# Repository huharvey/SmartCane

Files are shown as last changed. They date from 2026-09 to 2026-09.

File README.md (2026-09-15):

# SmartCane

基于 **ESP32-S3-CAM** 的智能拐杖课程原型：近障提示、跌倒告警、心率/血氧采集、Wi-Fi 图传、GPS 定位，以及 MQTT 远程监护网页。

本仓库是结题归档版本。固件对应实机调试最终代码；电路对应嘉立创工程 `智能拐杖电路设计_1.eprj2`；结构对应 `结构` 目录完整文件。跌倒检测与 MAX30102/节律筛查仅为课程演示，**不能作为医疗或人身安全认证结论**。

## 仓库结构

```text
SmartCane/
├─ firmware/          ESP32 固件、上位机、远程网页、验收材料
├─ hardware/          嘉立创电路工程、Gerber、原理图 PDF
├─ mechanical/        SolidWorks 零件/装配体、STEP、打印文件
├─ docs/              开题答辩、中期进展、结题报告（已去标识）
└─ media/             结构照片、调试截图、功能演示视频
```

| 路径 | 说明 |
|---|---|
| `firmware/` | PlatformIO / Arduino 主工程。详细说明见 [firmware/README.md](firmware/README.md) |
| `firmware/src/` | 驱动、FreeRTOS 任务、跌倒检测、MQTT、摄像头服务 |
| `firmware/upper_computer/` | Windows PyQt 上位机（串口遥测、图传、地图） |
| `firmware/remote_dashboard/` | MQTT 远程监护网页（Python） |
| `firmware/ml/rhythm/` | 节律筛查离线训练脚本（公开 MIMIC 数据包需自行下载） |
| `hardware/智能拐杖电路设计.eprj2` | 最终电路 PCB 工程 |
| `hardware/Gerber_PCB.zip` | 制板 Gerber |
| `mechanical/` | 壳体、装配体及厂商库模型（按结题结构目录原样归档） |
| `docs/` | 课程报告与答辩材料 |
| `media/videos/` | 心率血氧、跌倒告警、超声测距、实时图传 |

## 功能概览

- HC-SR04（I2C）、JY901S、ATGM336H、BH1750、SSD1306、SOS 按键、蜂鸣器、照明
- OV2640 MJPEG 图传与本地网页控制
- 双路径跌倒检测（冲击路径 + 深度失重补偿），SOS/跌倒锁存
- MAX30102 心率/血氧原型与端侧节律筛查（非医疗）
- MQTT TLS 公网遥测 + 独立远程监护网页
- 上位机：串口 JSON、图传、GPS 地图、轨迹导入

当前台架配置中，MAX30102 与超声波模块共用 I2C 地址 `0x57`，固件默认关闭超声波和 OLED，只启用 MAX30102。若要同时使用，必须在硬件上分离总线。

## 快速开始（固件）

1. 用 VS Code / PlatformIO 打开 `firmware/`。
2. 编辑 `firmware/src/config/UserConfig.h`：填写 Wi-Fi、高德静态地图 Key、MQTT Broker（仓库内均为空占位符）。
3. 选择 `esp32-s3-cam`，Build / Upload。板型为 GOOUUU ESP32-S3-CAM（8 MB Flash + OPI PSRAM），USB CDC On Boot 需关闭。
4. 串口 115200。上位机见 `firmware/upper_computer/README.md`。

热点回退（SSID 留空时）：

- SSID：`SmartCane-Camera`
- 密码：`12345678`
- 页面：`http://192.168.4.1/`

## 硬件要点

- 主控：ESP32-S3-CAM + OV2640
- I2C：SDA GPIO41、SCL GPIO42（3.3 V 上拉）
- IMU：GPIO39/38；GPS：GPIO47/21；SOS：GPIO40；蜂鸣器：GPIO1；照明：GPIO14
- 原理图 PDF 与 Gerber 在 `hardware/`；结构件在 `mechanical/`

## 归档说明

- 已移除学号、姓名等课程标识；报告正文中的姓名已替换为成员 A/B/C。
- Wi-Fi 密码、高德 Key、EMQX 账号已换成空占位符；MQTT 默认关闭。本地烧录前请自行填写。
- 运行日志、原始 MIMIC zip、含密钥的 `.bin` 固件未入库。
- 结题答辩 PPT 因体积超过 GitHub 单文件限制未放入仓库；开题/中期 PPT 与结题报告在 `docs/`。

## 许可与声明

课程项目归档，仅供学习交流。传感器告警、跌倒检测和生理信号结果均未经医疗器械验证。

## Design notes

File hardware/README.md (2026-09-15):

# 电路与 PCB

- `智能拐杖电路设计.eprj2`：嘉立创 EDA 最终工程（对应原 `智能拐杖电路设计_1.eprj2`）
- `Gerber_PCB.zip`：制板 Gerber
- `SCH_Schematic1.pdf` / `SCH_Schematic2.pdf` / `SCH_Schematic5.pdf`：原理图导出

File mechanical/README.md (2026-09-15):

# 结构件

结题时的完整结构目录归档，含自制壳体、装配体、STEP 以及厂商库模型。

主要文件：

- `装配体.SLDASM`：总装配
- `01_亚克力筒.SLDPRT`、`02_摄像头和灯泡载体.*`、`04_上半后部分.*`、`05_下半部分.*` 等自制件
- `电路连接件/`：主板底座、电池底座等
- `MAIN.step` / `UPPER.step` / `LOWER.step` / `POWER.step`：导出 STEP

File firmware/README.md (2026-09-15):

# ESP32-S3-CAM 智能拐杖 Arduino 工程

本目录是仓库中的固件子工程；项目总览见仓库根目录 [README.md](../README.md)。

本工程对应 **GOOUUU ESP32-S3-CAM + OV2640**，并按所给三页原理图配置引脚。传感器、决策、执行器、网络和串口已按 FreeRTOS 多任务运行；相机、Wi-Fi 和 HTTP 服务来自 ESP32 Arduino Core。

## 详细文档

- [工程架构与每个文件的作用](docs/01-工程架构与文件说明.md)
- [ESP32-S3 Arduino 开发与调试指南（零基础）](docs/02-ESP32-Arduino开发与调试指南.md)
- [ESP32-S3-CAM 每 10 秒 Wi-Fi 图传 Demo](demos/wifi_snapshot_10s/README.md)
- [上位机与 SC1 串口通信协议](docs/03-上位机与通信协议.md)
- [硬件现状与下一阶段特色方案](docs/04-硬件现状与下一阶段特色方案.md)
- [FreeRTOS 联调与测试操作手册](docs/06-FreeRTOS联调与测试操作手册.md)
- [跌倒确认与 MAX30102 调试](docs/07-跌倒确认与MAX30102调试.md)
- [TinyML 节律筛查与 MQTT 公网接入](docs/08-TinyML节律筛查与MQTT公网接入.md)
- [MAX30102 与节律筛查调试指南](docs/09-MAX30102与节律筛查调试指南.md)
- [MAX30102 首轮无参考仪器数据分析](docs/10-MAX30102首轮无参考仪器数据分析.md)
- [公网监护网页与部署说明](remote_dashboard/README.md)
- [本轮验收进展与后续任务](验收材料/SmartCane555_本轮代码改动_调试进展与后续任务.md)
- [Windows 上位机使用说明](upper_computer/README.md)

## 本次集成交付边界

已集成并作为本次交付验收项：各传感器原始数据采集、OLED/蜂鸣器/照明硬件接口、CH340 串口 JSON 遥测与命令、Wi-Fi 摄像头服务、上位机传感器显示、MJPEG 图传、GPS 地图和 GeoJSON/GPX/KML 导入。

本次还完成了双核 FreeRTOS 调度、队列/互斥保护、经独立样本验收的双路径跌倒检测、MAX30102 心率/血氧原型、PPG 质量与 baseline 节律筛查，以及 MQTT TLS 公网遥测和独立远程监护网页。跌倒阈值已按本项目样本冻结，但这些结果仍属于课程原型，不能作为医疗或人身安全认证结论。

公网网页曾部署到云主机做课程演示。仓库中的 MQTT / Wi-Fi / 地图密钥已清空，本地复现时请自行填写 `UserConfig.h` 与 `remote_dashboard/.env`。域名和 HTTPS 是后续安全升级项，不是课程演示的硬性前置条件。

## 给后续的阅读入口

1. 先看 `src/model/SystemState.h`：这是统一的传感器数据结构、单位和有效性约定；
2. 再看 `src/app/SmartCaneApp.cpp` 的 `updateSensors()`：这里汇总各驱动的新数据并处理超时；
3. 需要核对原始协议时再进入 `src/drivers/`，不要在算法中直接读 UART/I2C；
4. 算法建议在 `updateSensors()` 之后消费 `sensors_`，输出事件交给控制层；
5. 串口/HTTP 对外字段以 `docs/03-上位机与通信协议.md` 为准。

## 已实现功能

- HC-SR04 2021 UART/IIC 版：I2C 非阻塞测距，默认地址 `0x57`；当前 MAX30102 台架配置因地址冲突暂时停用
- JY901S：解析 `0x55` 帧的加速度、角速度和欧拉角
- ATGM336H：校验并解析 RMC/GGA NMEA 语句
- BH1750 GY-302：自动识别 `0x23`/`0x5C` 地址并读取照度
- SSD1306 128x64：自带轻量显示驱动和英数字体
- SOS 按键、蜂鸣器和照明 LED：分级节奏、锁存、取消及网页/串口控制已实现
- 跌倒检测：严格冲击路径与深度失重补偿路径已实现，并完成独立样本验收
- MAX30102：心率、血氧原型、PPG 质量、IBI/HRV 特征和佩戴状态检测
- 节律筛查：端侧特征提取与 baseline TinyML 推理链已接通；训练模型替换仍待完成
- MQTT 公网通信：通过 TLS 发布 presence、telemetry、vitals、gps、event 五类主题，远程控制默认关闭
- Wi-Fi：优先连接路由器，失败后建立 `SmartCane-Camera` 热点
- OV2640：网页 MJPEG 图传、JPEG 抓拍、JSON 状态和网页控制
- 上位机：串口全量遥测/控制、Wi-Fi 图传、GPS 在线/离线矢量地图、轨迹导入
- 公网监护网页：Python 后端订阅 MQTT，向浏览器提供只读状态、SSE 实时刷新、告警事件和 GPS 地图

> 跌倒检测和 MAX30102/节律筛查均为课程原型。现有验收只能说明在本项目采集样本中通过，不能替代医疗器械验证或真实人身安全认证。

## 引脚表

| 功能 | 模块/信号 | ESP32-S3 GPIO | 板卡排针 | 方向（以 ESP32 为准） |
|---|---|---:|---:|---|
| I2C SDA | 超声波、BH1750、OLED 共用 | 41 | U3-15 | 双向 |
| I2C SCL | 超声波、BH1750、OLED 共用 | 42 | U3-16 | 输出 |
| JY901S TX | IMU 数据到主控 | 39 | U3-13 | RX |
| JY901S RX | 主控命令到 IMU | 38 | U3-12 | TX |
| ATGM336H TX | GPS 数据到主控 | 47 | U3-5 | RX |
| ATGM336H RX | 主控命令到 GPS | 21 | U3-4 | TX |
| SOS | 按下为高电平 | 40 | U3-14 | 输入 |
| 蜂鸣器 | MOS 管栅极，高电平响 | 1 | U3-18 | 输出 |
| LED/照明 | 高电平开 | 14 | U2-19 | 输出 |

相机引脚按板卡原理图固定为：SCCB `GPIO4/5`、VSYNC `6`、HREF `7`、XCLK `15`、PCLK `13`、数据线 `8/9/10/11/12/16/17/18`。这些脚不可再分配给外围模块。

## 工程结构

```text
SmartCane/
├─ SmartCane.ino                 Arduino 入口
├─ platformio.ini                PlatformIO 构建配置
└─ src/
   ├─ app/                       初始化、非阻塞调度和数据发布
   ├─ config/                    板级引脚、Wi-Fi、采样周期
   ├─ control/                   跌倒检测和分级告警状态机
   ├─ drivers/                   每个传感器/执行器的独立驱动
   ├─ model/                     传感器与系统状态模型
   └─ services/                  Wi-Fi、HTTP、摄像头和 MJPEG
```

## 首次配置

编辑 `src/config/UserConfig.h`：

1. 如需连接家中路由器，填写 `WIFI_SSID` 和 `WIFI_PASSWORD`。
2. 留空 `WIFI_SSID` 时，设备直接建立热点：
   - 热点名：`SmartCane-Camera`
   - 密码：`12345678`
   - 默认页面：`http://192.168.4.1/`
3. 图像方向不对时调整 `CAMERA_VFLIP`、`CAMERA_HMIRROR`。
4. MAX30102 与 I2C 超声波模块默认都使用 `0x57`；当前台架只启用 MAX30102。若要同时使用，必须在硬件上分离总线或更换地址/接口，不能只靠软件消除地址冲突。
5. 公网功能应填写 EMQX Broker 地址和 MQTT 设备账号；ESP32 不直接连接 ECS 公网 IP。ECS 只运行远程监护后端。
6. 跌倒、避障和任务周期参数均在同一文件中修改；修改后按操作手册重新测试。

Wi-Fi、MQTT 和地图密钥会以明文进入配置或固件。准备公开代码、答辩归档或上传仓库前，应替换为占位符并重新生成已经暴露的密码。

## 编译和烧录

### PlatformIO（推荐）

用 VS Code/PlatformIO 打开本目录，选择 `esp32-s3-cam` 环境后执行 Build 和 Upload。配置已启用 8 MB Flash、OPI PSRAM 和 `min_spiffs` 分区。实测板使用 CH340 的 UART0（当前 COM8），因此 USB CDC On Boot 必须为 Disabled；COM 号变化时同步修改 `platformio.ini` 或让 PlatformIO 自动选择。

由于 Windows 版 ESP32 链接器对中文构建路径兼容性较差，`platformio.ini` 已把生成文件放到系统临时目录；源码仍保留在当前中文目录，不影响编辑和上传。

### Arduino IDE

1. 安装 Espressif 的 `esp32` 开发板包。
2. 打开 `SmartCane.ino`。
3. 选择 `ESP32S3 Dev Module`。
4. 建议设置：Flash 8MB、PSRAM `OPI PSRAM`、USB CDC On Boot `Disabled`、Partition Scheme `Minimal SPIFFS (Large APPS)`。
5. 上传后打开 115200 波特率串口监视器。

若首次下载失败，按住板上 BOOT，再点一下 RST，开始写入后松开 BOOT。

## 开机自检

串口会先输出 I2C 扫描结果。正常情况下常见地址为：

- `0x23` 或 `0x5C`：BH1750
- `0x3C`：SSD1306
- `0x57`：HC-SR04 IIC

随后应看到各设备的 `online` 状态和周期状态行。OLED 显示告警、距离、照度、GPS 卫星数及网页 IP。

JY901S 和 ATGM336H 没有 I2C 地址，应分别从串口数据判断在线。JY901S 默认按 9600 波特率配置；若模块曾被上位机改为其他波特率，请同步修改 `BoardConfig.h` 中的 `IMU_BAUD`。

## ESP32 本地网页接口

| 地址 | 方法 | 功能 |
|---|---|---|
| `/` | GET | 中文监控和控制页面 |
| `:81/stream` | GET | MJPEG 实时流 |
| `/capture` | GET | 单张 JPEG |
| `/api/status` | GET | 距离、照度、IMU、GPS、告警和网络 JSON |
| `/api/sos` | POST | 通过命令队列触发并锁存 SOS |
| `/api/cancel` | POST | 通过命令队列解除 SOS/FALL 锁存 |
| `/api/light?mode=on/off/auto` | GET | 通过命令队列切换照明模式 |

## 公网监护网页

`remote_dashboard/` 是独立的 Python MQTT 后端和前端，不把 MQTT 密码放进浏览器，也不依赖 ESP32 的局域网 IP。当前公网第一版为只读监护，提供 `/api/status`、`/api/state` 和 SSE `/api/stream`；摄像头仍只支持本地近场访问。部署、Nginx、公网 IP 演示和真实设备验收步骤见 [部署指南](remote_dashboard/DEPLOYMENT.md)。

## 跌倒检测和分级告警

优先级为 `SOS > FALL > DANGER <30 cm > WARNING <50 cm > CAUTION <100 cm > NORMAL`。SOS/FALL 会锁存，需 `CANCEL` 解除；近障在距离有效且离开阈值回差后自动解除。跌倒规则和调参步骤见 [操作手册](docs/06-FreeRTOS联调与测试操作手册.md)。

## 硬件注意事项

- I2C 上拉必须接到 3.3 V；所给原理图中的 4.7 kΩ 上拉符合要求。
- ESP32-S3 GPIO 不耐 5 V。确认 JY901S、GPS 和超声波输出是 3.3 V TTL/I2C；若某模块 TX/SDA/SCL 为 5 V，必须加电平转换。
- 蜂鸣器由原理图中的 MOS 管驱动，不应把蜂鸣器负载直接接到 GPIO。
- 相机启动电流和 Wi-Fi 发射峰值较大，5 V 电源应留有足够余量并保持地线可靠。
- `0x57` 驱动按“写 `0x01`，等待 130 ms（额定转换约 120 ms，留 10 ms 余量），读取 24 位微米值”的 2021 IIC 协议实现。如果你的模块标签/手册给出不同地址或数据单位，只修改 `Hcsr04I2c.cpp` 的命令或换算即可，其他控制逻辑无需改动。

## 建议的实机调试顺序

1. 不装相机，确认 I2C 三个地址、IMU 帧和 GPS NMEA 正常。
2. 遮挡/移开超声波，核对 OLED 距离和三档蜂鸣器节奏。
3. 遮住 BH1750，确认自动照明；再测试网页手动开、关、自动。
4. 室外等待 GPS 定位，检查网页经纬度和卫星数。
5. 最后接相机并测试图传；若此时复位，优先排查 5 V 供电压降。
6. 跌倒阈值已冻结；如更换 IMU、安装方向或拐杖结构，再重新采集正常/跌倒样本并回归。
7. 服务器先用演示模式检查公网登录；智能拐杖在场后关闭演示模式，使用手机 4G/5G 完成一次真实 MQTT 端到端验收。

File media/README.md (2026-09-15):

# 成果展示

## 结构

- `structure/assembly-1.jpg`
- `structure/assembly-2.jpg`

## 视频

| 文件 | 内容 |
|---|---|
| `videos/clip-overview.mp4` | 短览 |
| `videos/heart-spo2.mp4` | 心率 / 血氧测量 |
| `videos/fall-alarm.mp4` | 跌倒告警 |
| `videos/clip-fall.mp4` | 跌倒相关短片段 |
| `videos/ultrasonic.mp4` | 超声测距 |
| `videos/clip-ultrasonic.mp4` | 测距短片段 |
| `videos/camera-stream.mp4` | 实时图传 |

## 调试截图

`screenshots/` 为上位机与网页联调截图。

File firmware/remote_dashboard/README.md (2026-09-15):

# SmartCane 公网只读监护网页

该目录复用已经验证的 Python/MQTT 后端，将 ESP32 数据变成可通过公网查看的网站。当前课程演示采用“ECS 公网 IP + HTTP + Nginx”，域名与 HTTPS 作为后续安全升级；浏览器只连接 Python 后端，不会直接登录 MQTT。公网第一版没有 SOS、解除告警、灯光等远程控制入口。

## 目录

```text
remote_dashboard/
  frontend/
    index.html           # 从固件网页拆出的页面结构
    app.css              # 固件原有深色卡片配色与响应式布局
    app.js               # /api/status + /api/stream 数据刷新
  smartcane_remote/
    mqtt_bridge.py       # MQTT TLS，只订阅五个允许 Topic
    state.py             # 最新状态、最后有效 GPS、事件缓存
    amap.py              # 服务器端高德静态地图代理
  app.py                 # Flask API、SSE、网页登录保护
  compose.yaml           # 推荐的云服务器容器启动方式
  deploy/                # Nginx 与 systemd 示例
  DEPLOYMENT.md          # 从本机测试到手机 4G 验收的完整步骤
```

固件中的本地网页仍保留，用于 `192.168.4.1` 摄像头和近场调试；公网网页独立维护，不再把新的公网 HTML 塞回 ESP32 固件。

## 数据链路

```text
ESP32 -> MQTT TLS/8883 -> EMQX 公网 Broker
                              |
                       Python remote_dashboard
                              |
                  HTTP（当前）/HTTPS（可选）+ SSE
                              |
                       手机/电脑浏览器
```

后端只订阅：

- `smartcane/device01/presence`
- `smartcane/device01/telemetry`
- `smartcane/device01/vitals`
- `smartcane/device01/gps`
- `smartcane/device01/event`

## 本机演示

```powershell
cd remote_dashboard
Copy-Item .env.example .env
.\run.ps1 -Install
.\run.ps1 -Demo
```

浏览器打开 `http://127.0.0.1:8080`。演示模式不连接真实 Broker，会生成模拟心率、血氧、GPS 和事件。

连接真实 Broker 时，编辑 `.env`，把 `SMARTCANE_DEMO=false`，并填写 MQTT 只读账号。不要提交 `.env`；它已经被 `.gitignore` 与 `.dockerignore` 排除。

## HTTP 接口

- `GET /api/status`：兼容原固件网页使用习惯，返回 MQTT 缓存的云端状态。
- `GET /api/state`：与 `/api/status` 返回相同的规范化状态。
- `GET /api/stream`：SSE 实时状态流；15 秒无新消息时也会重算设备离线状态。
- `GET /api/map.png`：由服务器调用高德静态地图，不把地图 Key 发给浏览器。
- `GET /livez`：应用进程存活探针。
- `GET /readyz`：MQTT 是否已经连接的就绪探针。

没有 `/api/sos`、`/api/cancel` 或 `/api/light` 公网接口。

## 状态规则

- `presence=online`、telemetry 中 `online=true` 且 15 秒内更新：设备在线。
- telemetry 超过 15 秒：设备显示离线或数据超时。
- telemetry 同时显示超声波前方距离、BH1750 环境照度及两项传感器健康状态；数据无效或超过固件新鲜度期限时显示“离线/无数据”。
- GPS 失星或设备离线：继续显示后端保存的最后一次有效位置，并标成“最后位置”。
- NORMAL 为绿色；CAUTION/WARNING/DANGER 为黄色；疑似跌倒为橙色；SOS/FALL 为红色。
- 节律筛查是非医疗筛查；`model_calibrated=false` 时页面会明确显示“演示筛查，非医疗诊断”。
- 事件仅保存在进程内存中，服务重启后历史事件会清空；课程第一阶段可接受，长期使用应接数据库。

公网 IP 部署、登录账号、EMQX ACL、真实模式切换和手机 4G 验收见 [DEPLOYMENT.md](DEPLOYMENT.md)。本次实际部署状态见 [公网IP部署验收记录.md](公网IP部署验收记录.md)。

## 当前部署边界

- 已完成：ECS 上 Docker 容器健康运行、Nginx 80 端口反向代理、安全组关联、公网 IP 登录页访问。
- 当前模式：`SMARTCANE_DEMO=true`，页面数据由服务器模拟，并不代表实机已接入该网页。
- 待实机：将 `SMARTCANE_DEMO=false` 后，验证 ESP32 → EMQX → ECS → 4G/5G 浏览器的完整真实链路。
- 安全限制：HTTP Basic 登录在 HTTP 下不加密，只适合短期课程演示；真实健康和位置数据长期使用前应升级 HTTPS 或加密专网。

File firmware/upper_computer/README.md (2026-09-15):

# SmartCane 上位机

该程序同时完成三条数据链路：

- CH340 串口（115200 bit/s）：接收 5 Hz JSON 传感器遥测，保留设备控制命令入口；
- Wi-Fi HTTP/MJPEG：连接 ESP32-S3-CAM 的 81 端口实时流，断流时自动降级到 `/capture` 抓拍；
- GPS 地图：显示实时位置和轨迹，支持导入 GeoJSON、GPX、KML。

调试版还提供：自动识别 CH340/CP210x/FTDI 串口（排除蓝牙 COM）、自动保存
完整原始串口日志、启动自检解析、遥测超时告警，以及 IMU、MAX30102、摄像头、
MQTT 等模块的可视化健康判定。

地图底图使用按需加载的 OpenStreetMap 瓦片，并使用磁盘缓存；不会预下载地图。没有互联网时，底图变为暗色网格，但 GPS 点、实时轨迹和导入轨迹仍可正常显示。

## 1. 安装与启动

在本目录打开 PowerShell：

```powershell
.\run.ps1 -Install
.\run.ps1
```

只需安装一次依赖。也可以手动执行：

```powershell
python -m pip install -r requirements.txt
python main.py
```

无硬件验收界面：

```powershell
.\run.ps1 -Demo
```

## 2. 实机连接顺序

1. 给拐杖上电，将 CH340 USB 串口接到电脑。
2. 电脑连接设备热点 `SmartCane-Camera`，密码 `12345678`；若固件配置为路由器模式，则电脑和设备接入同一局域网。
3. 启动上位机，在左侧选择 COM 口并点击“连接”。当前实测板通常是 COM8，程序会自动列出所有端口。
4. 串口遥测中的 IP 会自动填入图传地址；点击“连接图传”。热点模式默认地址为 `http://192.168.4.1`。
5. GPS 室外定位后，右侧地图出现实时位置。可点击“导入地图/轨迹”加载 `.geojson`、`.gpx` 或 `.kml`。

默认勾选“自动发现并连接 USB-TTL”。插入设备后，上位机会忽略 Windows 的蓝牙
串口，优先选择 CH340、CP210x 或 FTDI；连接成功后在 `upper_computer/logs/`
自动创建 UTF-8 日志。若自动自检中的主 I²C/OLED 仍显示“等待”，按一次板上 RST，
让上位机重新抓取完整启动日志即可。状态说明：

- 绿色“正常”：日志或遥测已经确认该链路可用；
- 灰色“等待”：仍在启动、定位、联网或等待放置手指；
- 黄色“注意”：模块未接、数据无效或功能未启用，但核心串口仍可调试；
- 红色“异常”：核心链路超时、任务创建失败或 MQTT 配置/连接错误。

日志区右上角可打开日志目录、另存本次日志或清空当前屏幕显示；清空显示不会删除
磁盘中的原始日志。

串口或图传被其他监视器占用时，应先关闭原程序再连接。若 Windows 把本地地址交给代理软件，上位机的数据通道会主动绕过系统代理。

## 3. 控制入口

- 通信测试、立即遥测；
- SOS、解除告警和照明控制按钮仍保留，但当前主固件对应逻辑是 TODO 空实现；
- 保存当前 JPEG；
- 导入/清除地图轨迹、清除实时 GPS 轨迹、跟随 GPS。

## 4. 跌倒检测高频数据采集

左侧向下滚动到“跌倒检测 · 高频 IMU 数据采集”：

1. 填写唯一试验编号并选择场景；场景已经绑定 `normal/fall` 真实标签。
2. 点击“开始记录”，上位机发送 `SC1 CMD IMU STREAM ON`。
3. 保持直立基线约 5 秒后点击“动作开始”，下一条样本写入 `ACTION_START`。
4. 完成动作并保留约 5 秒尾段，点击“停止并保存”。

单次原始记录保存在 `upper_computer/imu_captures/imu_*.csv`，总试验索引保存在
`imu_captures/trials.csv`。界面自动显示真实采样率、源序号丢帧、最大采样间隔、
召回率和误报率。正常动作只要出现 `SUSPECTED_FALL` 即按 FP 统计；模拟跌倒
出现 `SUSPECTED_FALL` 或 `FALL` 即按 TP 统计。

曲线中的 A、G、Tilt 来自设备同一条新 IMU 样本，红色虚线对应当前固件阈值。
现有 5 Hz `SC1 TEL` 继续用于普通状态卡片，不用于冲击峰值标定。

## 5. MAX30102 PPG/血氧数据采集

左侧继续向下滚动到“MAX30102 · PPG/血氧数据采集”：

1. 填写 `P001` 形式的试验编号并选择场景；
2. 点击“开始记录”，上位机发送 `SC1 CMD PPG STREAM ON`；
3. 点击“动作/放指开始”，下一条样本写入 `ACTION_START`；
4. 按场景要求保持 15～90 秒，再点击“停止并保存”。

当前课程调试阶段未配置标准参考仪器，因此界面不提供 HR/SpO₂ 对照输入和 MAE 统计；
保存的数值只用于波形、稳定性和算法链路验证，不作为精度校准结论。

每条 FIFO 样本记录 RED/IR 原始值、DC/AC、滤波 IR、包络、候选峰、接受峰、
IBI、手指状态、SQI、HR、SpO₂、有效状态和 FIFO 溢出计数；同时合并最近一帧
节律特征、分类结果、推理耗时、模型/状态内存和 IMU 运动量。CSV 保存在
`upper_computer/ppg_captures/`。

当前 ADC 设置为 100 SPS，但传感器启用了 4 点硬件平均与抽取，所以 FIFO 的真实
目标输出率为 25 Hz，即约 40 ms/样本。IMU 与 PPG 高频串口流互斥，避免占满
115200 bit/s 串口。

曲线含 RED/IR AC、滤波 IR、接受的脉搏峰和 SQI。详细试验顺序、数据量、HR/SpO₂
对照方法及节律公开数据训练要求见 `docs/09-MAX30102与节律筛查调试指南.md`。

## 6. 文件结构

```text
upper_computer/
├─ main.py                         程序入口和演示参数
├─ requirements.txt               Python 依赖
├─ run.ps1                         Windows 启动脚本
├─ smartcane_host/
│  ├─ protocol.py                 SC1 串口协议解析与命令白名单
│  ├─ serial_worker.py            串口后台线程
│  ├─ imu_capture.py              CSV、试验索引、召回率和误报率统计
│  ├─ imu_plot.py                 A/G/Tilt 实时曲线与阈值线
│  ├─ ppg_capture.py              PPG CSV 和信号质量统计
│  ├─ ppg_plot.py                 RED/IR、滤波波形、峰值与 SQI 曲线
│  ├─ camera_worker.py            MJPEG 接收与抓拍降级
│  ├─ track_import.py             GeoJSON/GPX/KML 解析
│  ├─ map_widget.py               在线瓦片、缓存、离线矢量地图
│  └─ main_window.py              三栏监控界面
├─ samples/demo_track.geojson      导入测试文件
└─ tests/                           协议与轨迹解析测试
```

## 7. 交付边界

上位机只展示固件发来的原始/当前快照，不在电脑端实现跌倒判断、传感器融合或业务状态机。界面的告警字段直接显示固件结果。FreeRTOS任务划分、跌倒检测算法、传感器进一步处理和最终主状态机不在本次验收范围。

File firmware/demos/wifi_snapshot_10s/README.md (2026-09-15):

# ESP32-S3-CAM 每 10 秒 Wi-Fi 图传 Demo

## 1. 功能

本 Demo 是“定时快照图传”，不是连续视频流：

1. ESP32-S3-CAM 每 10 秒采集一张 JPEG 并缓存在 PSRAM；
2. Qt 上位机每 10 秒通过 HTTP 获取最新缓存帧；
3. 上位机显示帧号、大小、网络耗时、设备采集时刻和下次请求倒计时；
4. JPEG 可自动保存到电脑；
5. 固件内置浏览器页面，不打开 Qt 也能看图；
6. 附带本地模拟相机，无开发板时也能测试 Qt 上位机。

采用“ESP 定时采集 + PC 定时拉取”而不是 UDP 裸数据，是因为 JPEG/HTTP 更容易调试，丢包后下一周期可自动恢复，并且浏览器、Qt、Python 都能直接访问。

## 2. 目录

```text
wifi_snapshot_10s/
├─ firmware/
│  ├─ platformio.ini
│  ├─ include/
│  │  ├─ CameraPins.h
│  │  └─ DemoConfig.h
│  └─ src/main.cpp
├─ pc/
│  ├─ qt_receiver.py
│  ├─ mock_camera_server.py
│  ├─ requirements.txt
│  └─ run_mock_demo.ps1
└─ artifacts/
```

## 3. 默认联网方式

`DemoConfig.h` 默认不连接路由器，而是由开发板建立热点：

| 项目 | 默认值 |
|---|---|
| 热点名 | `ESP32-CAM-10S` |
| 密码 | `12345678` |
| 设备地址 | `http://192.168.4.1` |
| 采集周期 | 10000 ms |

电脑连接该热点后，可访问：

| 地址 | 功能 |
|---|---|
| `http://192.168.4.1/` | 内置浏览器上位机 |
| `http://192.168.4.1/capture` | 最新 JPEG |
| `http://192.168.4.1/api/status` | 帧号、大小、采集时刻和间隔 JSON |

如果希望开发板连接现有路由器，在 `firmware/include/DemoConfig.h` 填写 `WIFI_SSID` 和 `WIFI_PASSWORD`。真实密码不要提交到公开仓库。

## 4. 编译与烧录

用 VS Code 单独打开 `firmware` 文件夹，选择环境 `esp32-s3-cam-demo`：

```powershell
pio run -e esp32-s3-cam-demo
pio run -e esp32-s3-cam-demo -t upload
pio device monitor -b 115200
```

当前 Demo 针对带 CH340 的板卡，让 `Serial` 走 UART0。若上传一直停在 `Connecting...`：

1. 按住 BOOT；
2. 短按并松开 RST；
3. 松开 BOOT；
4. 重新上传。

正常日志示例：

```text
[Demo] ESP32-S3-CAM 10-second snapshot server
[Camera] ready, psram=yes
[WiFi] AP ESP32-CAM-10S, password 12345678, IP 192.168.4.1
[Frame] id=1 size=... capturedAt=...ms
[HTTP] open http://192.168.4.1/
```

之后每 10 秒帧号增加一次。

## 5. 运行 Qt 上位机

本机已有 PyQt5 时：

```powershell
cd pc
python qt_receiver.py --url http://192.168.4.1 --interval 10
```

缺少依赖时：

```powershell
python -m pip install -r requirements.txt
```

点击“开始接收”后会立即取第一张图，之后每 10 秒更新。勾选“自动保存 JPEG”时，图像写入 `pc/captures/`。

## 6. 无硬件模拟运行

`run_mock_demo.ps1` 会启动本地模拟相机、运行 Qt 12 秒、接收至少两轮定时帧，并保存窗口截图：

```powershell
powershell -ExecutionPolicy Bypass -File .\pc\run_mock_demo.ps1
```

也可分两个终端运行：

```powershell
python pc/mock_camera_server.py --port 8765 --interval 10
python pc/qt_receiver.py --url http://127.0.0.1:8765 --interval 10
```

## 7. 修改采集周期

ESP32 固件的真实采集周期在 `DemoConfig.h`：

```cpp
constexpr uint32_t CAPTURE_INTERVAL_MS = 10000;
```

Qt 请求周期由 `--interval` 设置。两者建议保持一致。若 Qt 更快，它会重复收到同一个 `X-Frame-Id`；若 Qt 更慢，它只会收到当前最新帧。

## 8. 常见问题

| 现象 | 处理 |
|---|---|
| Qt 显示连接失败 | 确认电脑连接 `ESP32-CAM-10S`，地址为 `192.168.4.1` |
| 能开网页但没有图 | 先访问 `/api/status`，再检查相机排线、引脚和供电 |
| 帧号不增加 | 查看串口是否每 10 秒出现 `[Frame]` |
| 图像颠倒 | 修改 `CAMERA_VFLIP` 或 `CAMERA_HMIRROR` |
| 相机初始化失败 | 断电重插排线，确认 OPI PSRAM 和稳定 5 V 供电 |
| 开相机后复位 | 换短数据线或更强电源，断开其他大电流负载 |
| Qt 无法启动 | 执行 `python -c "import PyQt5"` 并按 requirements 安装依赖 |

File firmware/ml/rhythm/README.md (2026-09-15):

# 智能拐杖异常节律候选模型训练

这套脚本把公开的 MIMIC PERform AF PPG 数据处理成与 ESP32 固件一致的 6 个轻量特征，按受试者划分训练、验证和独立测试集合，训练二分类逻辑回归，再量化为 ESP32 可直接使用的 INT8 参数。它还会回放已有 P001～P043 数据，检查正常和伪影场景是否出现新增严重假报警。

> 这是课程项目的风险筛查，不是医疗器械，也不能诊断房颤。最终提示必须使用“疑似异常节律/建议复测或就医”，不能写成“确诊房颤”。

## 需要的两个官方数据包

必须同时具备：

- `mimic_perform_af_csv.zip`：19 名房颤受试者；MD5 `df323c2be9db41589b5011ac9efb54ca`
- `mimic_perform_non_af_csv.zip`：16 名非房颤受试者；MD5 `84d5ad5e9fe94e83b40d6dbd36e4210e`

官方下载页：https://zenodo.org/records/6807403

只有 AF 包不能训练，因为模型必须同时看到“异常”和“正常”两类样本。脚本会在运行前校验两个文件的 MD5，防止断点下载留下损坏文件。

## Windows 操作

最省事的方法是不使用 PowerShell 脚本，直接在 CMD 或 VS Code 终端运行一键批处理（第二个参数是已有 P001～P043 数据目录）：

```bat
prepare_and_train.cmd "<local-path>\mimic_perform_af_csv.zip" "<local-path>\SmartCane_实机调试\SmartCane\验收材料\MAX30102与节律筛查验收\01-采集数据"
```

它会下载缺少的非房颤包、创建独立 Python 环境、安装依赖并执行训练。若下载中断，可再次运行；已经完整存在的包不会重复下载，训练脚本还会做 MD5 校验。

如果希望逐步操作，再使用下面的命令。

在 VS Code 的 PowerShell 终端中进入工程：

```powershell
Set-Location "<local-path>\SmartCane_实机调试\SmartCane\ml\rhythm"
py -3 -m venv .venv
Set-ExecutionPolicy -Scope Process Bypass
.\.venv\Scripts\Activate.ps1
python -m pip install -r requirements.txt
```

然后运行（按实际下载位置修改两个 zip 路径）：

```powershell
python .\run_training.py `
  --af-zip "<local-path>\mimic_perform_af_csv.zip" `
  --non-af-zip "<local-path>\mimic_perform_non_af_csv.zip" `
  --local-captures "<local-path>\SmartCane_实机调试\SmartCane\验收材料\MAX30102与节律筛查验收\01-采集数据" `
  --output ".\artifacts\latest"
```

首次运行要解析数十段波形，耗时会明显长于后续运行。第二次默认复用 `public_features.csv`；需要重新提取时加 `--rebuild-features`。

## 输出文件怎么看

- `TRAINING_REPORT.md`：最先阅读的中文结论。
- `metrics.json`：完整测试指标、受试者划分和量化参数。
- `dataset_manifest.json`：数据包哈希、每个受试者可用窗口数。
- `public_test_predictions.csv`：只含从未参与训练/调参的测试受试者结果。
- `local_replay.csv` / `local_replay_summary.json`：P001～P043 软件回放结果。
- `RhythmModel.generated.h`：候选 INT8 参数；只有报告允许进入实物回归时才接入固件。
- `check_hardware_regression.py`：烧录后检查最后 2～3 组实物记录。
- `HARDWARE_REGRESSION_CHECKLIST.md`：拿到开发板后逐项照做的操作单。

## 为什么不能训练完就把 calibrated 改成 true

公开数据的传感器、佩戴位置和人群与本项目 MAX30102 不完全相同。即使公开测试达标，仍须：

1. 接入候选参数并编译烧录；
2. 检查模型字节数、RAM、Flash 和推理耗时；
3. 重新采 2～3 组 30～60 秒正常静止 PPG；
4. 确认端侧最终为 `NORMAL` 且没有新增严重假报警；
5. 最后才把 `RHYTHM_MODEL_CALIBRATED` 设为 `true`。

脚本不会自动修改这个开关。

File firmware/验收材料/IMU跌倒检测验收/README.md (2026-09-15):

# 智能拐杖 IMU 跌倒检测验收说明

## 1. 验收结论

本目录归档了 JY901S IMU 接入、高频串口采集、阈值标定、状态机离线重放、固件实现和冻结参数独立验证的相关材料。

冻结参数后的独立验收共取得 17 份原始记录。其中 1 份后向倾倒记录在动作完成前停止，按预先定义的数据完整性规则标记为无效，并保留原文件；其后重新完成后向倾倒测试。因此最终有效验收集为：

- 正常动作：12 次，误报 0 次；
- 模拟跌倒：4 次，检出 4 次；
- 有效集混淆矩阵：TP=4、FN=0、FP=0、TN=12；
- 本轮受控场景召回率：100%；
- 本轮受控场景误报率：0%；
- 前向倾倒进一步完成了 `SUSPECTED_FALL → FALL` 的约 4 秒确认和锁存验证；
- 严格冲击路径与深度失重路径均在实机数据中得到验证。

据此，当前实现满足课程设计/工程原型的 IMU 跌倒检测交付要求。该结论仅适用于本机、当前安装方式和受控场景，不代表医疗或真实人群安全认证结果。

## 2. 最终冻结参数

参数定义见 `04-固件关键代码/UserConfig.h`。

| 参数 | 冻结值 | 作用 |
|---|---:|---|
| `FALL_FREE_FALL_G` | 0.55 g | 普通低重力候选入口 |
| `FALL_DEEP_FREE_FALL_G` | 0.40 g | 未采到冲击峰值时的深度失重入口 |
| `FALL_IMPACT_G` | 2.20 g | 严格路径冲击阈值 |
| `FALL_TILT_DEG` | 55° | 横滚或俯仰倾斜阈值 |
| `FALL_STILL_GYRO_DPS` | 45°/s | 倾倒后静止角速度上限 |
| `FALL_TILT_HOLD_MS` | 600 ms | 严格路径持续保持时间 |
| `FALL_DEEP_TILT_HOLD_MS` | 1200 ms | 深度失重路径持续保持时间 |
| `FALL_SEQUENCE_WINDOW_MS` | 2000 ms | 候选动作总窗口 |
| `SUSPECTED_FALL_CONFIRM_MS` | 4000 ms | 疑似跌倒转锁存跌倒等待时间 |
| `FALL_CANCEL_COOLDOWN_MS` | 3000 ms | 取消后的重复触发抑制时间 |

最终规则包含两条路径：

1. 严格路径：低重力或冲击进入候选，必须采到不低于 2.20 g 的冲击，随后倾角不低于 55°、合角速度不高于 45°/s，并连续保持 600 ms。
2. 深度失重路径：若采到不高于 0.40 g 的深度失重，即使 10 Hz 数据未采到冲击峰值，也可在相同倾斜和静止条件连续保持 1200 ms 后确认。

任一路径确认后先进入 `SUSPECTED_FALL`，4 秒内允许取消；未取消则锁存为 `FALL`。

## 3. 数据采集与调试过程

Qt 上位机通过 USB-TTL 接收固件输出的 `SC1 IMU` CSV。固件只在收到 JY901S 新样本时输出记录，实际采样率约 10 Hz；跌倒状态机在 ESP32 决策任务中每 20 ms 更新一次。

每条 CSV 包含：

- PC 时间、设备时间、试验编号、场景标签和真实标签；
- 三轴加速度、三轴角速度、横滚角、俯仰角和航向角；
- `A`、`G`、`Tilt` 三个派生量；
- 候选阶段、低重力、冲击、倾斜静止状态；
- `NORMAL`、`SUSPECTED_FALL`、`FALL` 告警状态；
- 序号、采样率、丢帧和最大间隔统计。

共进行了四个阶段：

| 阶段 | 文件数 | 用途 | 结果说明 |
|---|---:|---|---|
| 第1轮 | 16 | 初始场景采集 | 12 个正常场景和 4 个方向倾倒 |
| 第2轮 | 16 | 重复动作并暴露漏检 | 发现 10 Hz 下冲击峰值可能漏采 |
| 第3轮 | 16 | 双路径候选参数验证 | 发现前向倾倒最低加速度 0.3823 g，推动深度阈值冻结为 0.40 g |
| 第4轮 | 17 | 冻结参数独立验收 | 16 条有效记录全部通过，另有 1 条中止记录保留并重测 |

前三轮共 48 条记录参与了参数分析。最终参数对前三轮数据进行离线重放后，12 次模拟跌倒均检出，36 次正常动作均未误报。第4轮用于冻结参数后的实机独立验收。

## 4. 独立验收结果

第4轮原始数据位于 `01-采集数据/第4轮-冻结参数独立验收/`。

### 4.1 正常场景

以下 12 个场景均未进入 `SUSPECTED_FALL`：

1. 静止直立；
2. 正常行走；
3. 快速行走；
4. 大幅摆杖；
5. 左转；
6. 右转；
7. 上台阶；
8. 下台阶；
9. 靠墙放置；
10. 正常放下；
11. 正常拿起；
12. 杖尖碰撞。

其中快速行走最低加速度达到 0.4611 g、最高加速度达到 2.0322 g，曾进入普通候选阶段，但没有满足冲击确认和倾斜静止保持条件，因此未误报。正常放下和拿起的最大倾角分别达到约 91° 和 96°，但没有低重力/冲击事件链，也未误报。

### 4.2 模拟跌倒

| 方向 | 文件 | 触发路径 | 结果 |
|---|---|---|---|
| 前向 | `imu_20260831_185116_533_T013_fall_forward.csv` | 严格/双重保持 | 进入疑似跌倒，并在约 4 秒后锁存 `FALL` |
| 后向 | `imu_20260831_185218_860_T015_fall_backward.csv` | 深度失重路径 | 进入疑似跌倒 |
| 左向 | `imu_20260831_185239_500_T016_fall_left.csv` | 深度失重路径 | 进入疑似跌倒 |
| 右向 | `imu_20260831_185307_771_T017_fall_right.csv` | 严格/双重保持 | 进入疑似跌倒；仅丢 1 帧，不影响结果 |

### 4.3 无效记录说明

`imu_20260831_185152_141_T014_fall_backward.csv` 为一次中止记录：

- 总记录时长仅 2.59 秒；
- 动作真正开始后约 200 ms 即停止保存；
- 最后倾角仅 45.43°，未达到冻结阈值 55°；
- 没有记录到落地后的静止保持段；
- 因此该文件不具备判定算法检出或漏检的完整条件。

该文件未被删除，保留用于审计；随后重新完成的后向倾倒记录为 `T015`，并通过深度失重路径触发。

## 5. 验收截图

### 5.1 正常上台阶

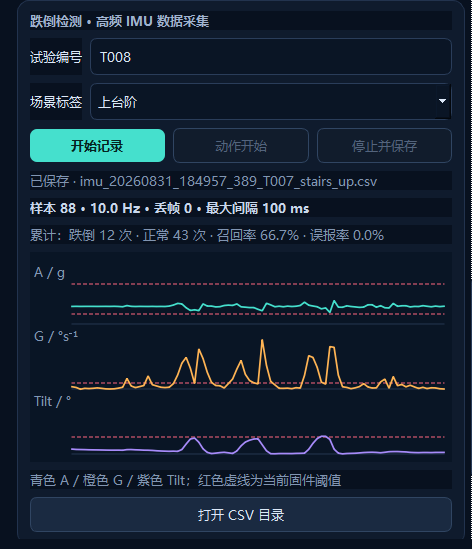
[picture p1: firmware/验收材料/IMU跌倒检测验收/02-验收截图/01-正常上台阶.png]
正常上台阶


### 5.2 正常放下

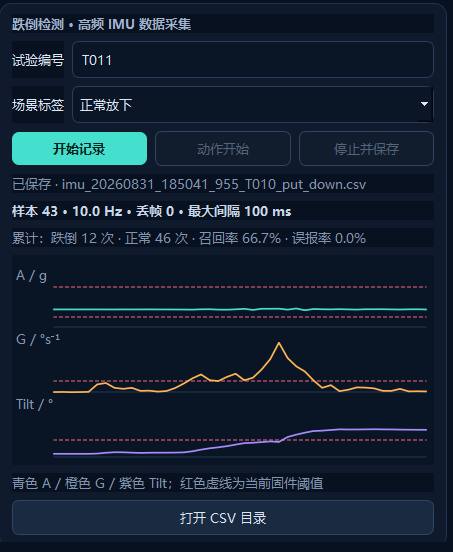
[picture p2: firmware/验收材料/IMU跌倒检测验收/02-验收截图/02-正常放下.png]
正常放下


### 5.3 前向跌倒

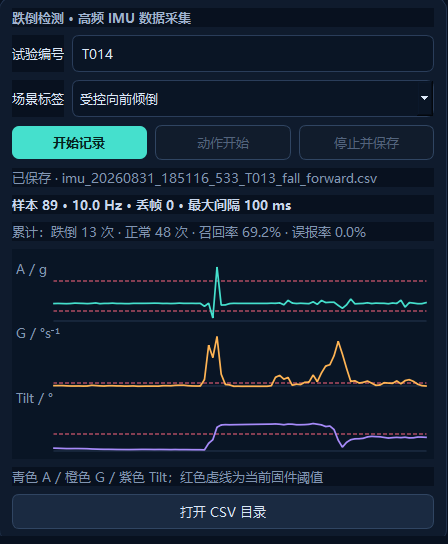
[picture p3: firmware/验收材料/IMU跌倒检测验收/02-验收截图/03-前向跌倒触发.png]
前向跌倒触发


### 5.4 后向跌倒

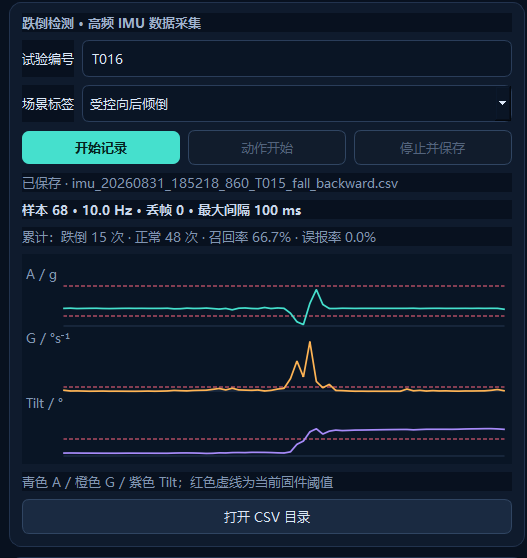
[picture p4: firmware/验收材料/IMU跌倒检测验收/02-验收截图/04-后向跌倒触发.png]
后向跌倒触发


## 6. 离线重放与网格扫描

`03-离线分析工具/` 保存了状态机重放器、网格扫描入口、测试和一份独立的 CSV 副本。

重放器不是简单按 10 Hz 的 CSV 行判断，而是在相邻样本之间保持上一帧，并按固件的 20 ms 决策周期更新状态机，从而复现持续保持时间和序列窗口。

在 `03-离线分析工具` 目录运行：

```powershell
python fall_grid_search.py
python -m pytest tests\test_fall_replay.py -q
```

工具目录中的 `imu_captures` 是64条有效记录的分析副本；排除项及理由见 `03-离线分析工具/EXCLUSIONS.md`。被排除的原始文件仍保存在第4轮原始数据目录中。

最终参数重放结果：

- 前三轮：TP=12、FN=0、FP=0、TN=36；
- 加入第4轮16条有效数据后：模拟跌倒 16/16 检出，正常动作 48/48 未误报；
- 第4轮中止记录不参与有效集统计。

## 7. 目录结构

```text
IMU跌倒检测验收/
├─ README.md
├─ 01-采集数据/
│  ├─ trials.csv
│  ├─ 第1轮-初始采集/
│  ├─ 第2轮-重复采集/
│  ├─ 第3轮-候选参数/
│  └─ 第4轮-冻结参数独立验收/
├─ 02-验收截图/
├─ 03-离线分析工具/
├─ 04-固件关键代码/
├─ 05-Qt上位机采集代码/
├─ 06-串口日志/
├─ 07-最终固件/
└─ 08-参考文档/
```

各目录内容如下：

- `01-采集数据`：全部原始 IMU CSV 和汇总表，不修改原始测量值；
- `02-验收截图`：正常动作与跌倒触发的 Qt 曲线截图；
- `03-离线分析工具`：状态机重放、参数扫描、测试和可直接运行的数据副本；
- `04-固件关键代码`：JY901S 驱动、双路径跌倒检测、最终配置和串口输出代码；
- `05-Qt上位机采集代码`：串口协议解析、CSV 采集、实时曲线和相关测试；
- `06-串口日志`：调试期间保存的原始上位机串口日志；
- `07-最终固件`：最终 ESP32-S3 `firmware.bin` 和 PlatformIO 配置；
- `08-参考文档`：通信协议、控制逻辑、FreeRTOS 联调和跌倒调试文档。

## 8. 构建与测试状态

- Qt/离线工具自动测试：21 项通过；
- PlatformIO 环境：`esp32-s3-cam`；
- 固件构建：成功；
- RAM 使用率：16.8%；
- Flash 使用率：51.4%；
- 串口 IMU 采样：约 10 Hz；
- 最终验收有效记录：全部有动作标记，无序列重置；右向倾倒仅出现 1 帧丢失。

## 9. 交付表述建议

建议在课程报告中使用以下表述：

> 冻结参数后完成一轮独立受控场景验证，共获得 16 组有效记录，包括 12 组正常动作和 4 组四方向模拟跌倒。正常动作均未触发跌倒报警，四方向模拟跌倒均进入疑似跌倒状态，其中前向试验进一步验证了 4 秒确认及 `FALL` 锁存流程。另有 1 次后向试验因记录在动作完成前停止而作废，随后重新测试通过。本系统已满足课程设计原型的跌倒检测交付要求。

不要将本轮结果表述为面向真实人群的“准确率 100%”或安全认证结果。可表述为“本轮受控场景通过率 100%”。

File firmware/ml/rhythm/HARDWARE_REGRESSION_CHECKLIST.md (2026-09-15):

# 候选节律模型：最后的实机短程回归

## 已完成的部分

- 候选模型已写入 `src/control/RhythmModel.generated.h` 并接入 `RhythmClassifier.cpp`。
- `RHYTHM_MODEL_CALIBRATED` 仍为 `false`，这是当前正确状态。
- PlatformIO `esp32-s3-cam` 编译已通过。
- 本次完整固件 RAM：`55308 / 327680 bytes（16.9%）`。
- 本次完整固件 Flash：`1012797 / 1966080 bytes（51.5%）`。
- 候选模型常量：`18 bytes`（不含分类器运行状态）。

## 拿到实机后按顺序操作

1. 在设备管理器或 PlatformIO Devices 中确认开发板当前 COM 口。
2. 将 `platformio.ini` 的 `upload_port` 和 `monitor_port` 改为该端口；不要照抄旧电脑的 COM8。
3. 关闭占用串口的串口监视器、Qt 上位机或其他程序。
4. 在 VS Code 的 PlatformIO 页面点击 Upload，或运行 `pio run -e esp32-s3-cam -t upload`。
5. 烧录结束后再打开串口监视器，确认启动日志无崩溃，MAX30102 在线。
6. 启动现有 Qt 上位机。若 PowerShell 禁止脚本，可在 `upper_computer` 中运行：

   ```powershell
   powershell -ExecutionPolicy Bypass -File .\run.ps1 -Install
   powershell -ExecutionPolicy Bypass -File .\run.ps1
   ```

7. 在“MAX30102 · PPG/血氧数据采集”中采 `P044`、`P045`、`P046` 三组 `rhythm_normal`：每组 45～60 秒，手指稳定覆盖，拐杖和手臂尽量静止；三组之间重新放置一次手指。
8. 正常现象：开始约 15 秒为 `COLLECTING`，之后允许短暂 `INCONCLUSIVE`，每组最后一次有效推理应为 `NORMAL`；全程不能出现 `SUSPECTED_AF`。
9. 用下列命令自动统计模型字节数、最终状态以及推理耗时平均值/P95/最大值：

   ```powershell
   Set-Location "<local-path>\SmartCane_实机调试\SmartCane\ml\rhythm"
   .\.venv\Scripts\python.exe .\check_hardware_regression.py `
     --captures "<local-path>\SmartCane_实机调试\SmartCane\upper_computer\ppg_captures" `
     --trials P044 P045 P046 `
     --output ".\artifacts\latest\HARDWARE_RESULT.md"
   ```

10. 打开 `artifacts/latest/HARDWARE_RESULT.md`。只有总体结论为“通过”，人工检查 CSV 也无异常后，才将 `src/config/UserConfig.h` 中的 `RHYTHM_MODEL_CALIBRATED` 改成 `true`，然后重新编译烧录。

## 状态含义

- 模型直接输出两类：`NORMAL` 或 AF-like。
- 第 1、2 个连续 AF-like 窗口只显示 `IRREGULAR`。
- 第 3 个连续 AF-like 窗口才显示 `SUSPECTED_AF` 并形成远程事件。
- 它不会自动触发 SOS、跌倒告警、蜂鸣器或摄像头。
- “通过”只说明课程原型的软件与短程实机回归完成，不等于医学诊断或医疗器械认证。

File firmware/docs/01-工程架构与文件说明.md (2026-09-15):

# SmartCane 工程架构与文件说明

> 本次集成验收只覆盖硬件驱动、原始数据通道、显示/执行器接口、串口、Wi-Fi图传和上位机。双核 FreeRTOS、跌倒检测和分级告警当前只保留空接口与中文 TODO，不包含基础实现。

## 1. 文档目的

本文面向需要阅读、维护或二次开发本工程的人员，说明：

- 工程实现了什么；
- 软件为什么这样分层；
- 系统从上电到稳定运行经历了什么；
- 传感器数据、告警命令和网页请求如何流动；
- 工程中每一个文件的职责以及修改边界。

配套的环境搭建、烧录和排错步骤见 [02-ESP32-Arduino开发与调试指南.md](./02-ESP32-Arduino开发与调试指南.md)。

## 2. 工程概况

SmartCane 是基于 **GOOUUU ESP32-S3-CAM + OV2640** 的智能导盲拐杖 Arduino 工程，使用 PlatformIO 组织和构建。当前功能包括：

- HC-SR04 2021 UART/IIC 版非阻塞测距；
- BH1750 环境照度采集；
- JY901S 加速度、角速度和姿态角解析；
- ATGM336H GPS 定位与 NMEA 解析；
- SSD1306 128×64 OLED 状态显示；
- 跌倒检测和分级告警接口占位（暂未实现）；
- Wi-Fi 路由器模式与自动回退热点模式；
- OV2640 单张抓拍、MJPEG 视频流、网页监控和远程控制。

工程采用 Arduino 框架，但没有把所有逻辑堆在一个 `.ino` 文件中。源码按应用、配置、控制、驱动、数据模型和服务分层，便于单独替换传感器或调整算法。

## 3. 技术栈与构建目标

| 项目 | 当前配置 |
|---|---|
| 主控 | ESP32-S3 |
| PlatformIO 环境名 | `esp32-s3-cam` |
| PlatformIO 开发板 ID | `esp32-s3-devkitc-1` |
| 软件框架 | Arduino for ESP32 |
| Flash | 8 MB |
| Flash/PSRAM 模式 | QIO Flash、OPI PSRAM |
| 分区表 | `min_spiffs.csv` |
| 调试串口 | 115200 bit/s |
| 主循环模型 | 非阻塞轮询调度 |
| 网络服务 | ESP-IDF `esp_http_server` |
| 并发同步 | 暂未实现，保留 TODO |

`platformio.ini` 把构建目录放到系统临时目录，是为了避开 Windows 版 ESP32 链接器对中文路径兼容性不稳定的问题。源码仍保留在当前中文目录中。

## 4. 总体架构

```mermaid
flowchart TD
    Entry["入口层<br/>SmartCane.ino / src/main.cpp"] --> App["应用协调层<br/>SmartCaneApp"]
    App --> Model["数据模型<br/>SensorSnapshot / AlarmKind"]
    App --> Control["控制层<br/>FallDetector / AlarmController"]
    App --> Drivers["驱动层<br/>I2C / UART / GPIO / OLED"]
    App --> Service["服务层<br/>Wi-Fi / Camera / HTTP / MJPEG"]

    Drivers --> Hardware["硬件<br/>超声波、BH1750、JY901S、GPS、OLED、按键"]
    Control --> Outputs["执行器<br/>蜂鸣器、照明 LED"]
    Service --> Camera["OV2640"]
    Service --> Browser["浏览器 / API 客户端"]

    Service -. "命令队列" .-> App
    App -. "受互斥量保护的状态快照" .-> Service
```

### 4.1 分层职责

| 层级 | 目录/文件 | 主要职责 | 不应承担的职责 |
|---|---|---|---|
| 入口层 | `SmartCane.ino`、`src/main.cpp` | 提供 Arduino 的 `setup()` 和 `loop()` | 不写业务逻辑 |
| 应用层 | `src/app/` | 初始化、周期调度、模块协作、状态发布 | 不直接解析设备协议 |
| 配置层 | `src/config/` | 引脚、波特率、Wi-Fi、阈值和周期参数 | 不执行控制流程 |
| 控制层 | `src/control/` | 跌倒检测和告警接口占位 | 暂无控制逻辑 |
| 驱动层 | `src/drivers/` | 设备协议、采样、校验、GPIO 输出 | 不决定业务告警等级 |
| 模型层 | `src/model/` | 模块间共享的数据结构和枚举 | 不读写硬件 |
| 服务层 | `src/services/` | Wi-Fi、摄像头、HTTP、网页和 API | 不直接修改主循环状态 |

这种划分使“更换一个传感器”和“修改告警策略”互不干扰。例如，超声波模块换协议时主要修改 `Hcsr04I2c.*`，距离告警阈值仍由 `AlarmController` 和 `UserConfig.h` 管理。

## 5. 双入口设计

工程同时保留两个入口，但一次构建只启用一个：

- Arduino IDE 使用根目录的 `SmartCane.ino`；
- PlatformIO 使用 `src/main.cpp`。

`platformio.ini` 定义了 `SMARTCANE_PLATFORMIO=1`，并通过 `build_src_filter` 排除 `SmartCane.ino`。同时两个入口内部还用条件编译保护：

```cpp
#ifndef SMARTCANE_PLATFORMIO  // 只给 Arduino IDE
#ifdef SMARTCANE_PLATFORMIO   // 只给 PlatformIO
```

因此不会出现两个 `setup()` 或两个 `loop()` 导致的重复定义错误。两个入口最终都只做两件事：

```cpp
void setup() { app.begin(); }
void loop()  { app.update(); }
```

## 6. 上电初始化流程

`SmartCaneApp::begin()` 按以下顺序执行：

1. 保存应用单例指针，供静态 HTTP 回调转回对象方法；
2. 启动 115200 波特率调试串口；
3. 初始化蜂鸣器、照明 LED 和 SOS 按键；
4. 在 GPIO41/42 上启动 100 kHz I2C，并扫描总线地址；
5. 初始化 BH1750、HC-SR04 IIC 和 SSD1306；
6. 启动 JY901S 使用的 UART1 和 GPS 使用的 UART2；
7. 预留双核 FreeRTOS 任务、队列和互斥量的位置（当前不创建、不运行）；
8. OLED 显示启动画面；
9. 启动 Wi-Fi 状态机；
10. 发布第一份系统状态快照，进入主循环。

典型串口启动信息为：

```text
[SmartCane] boot
[I2C] devices: 0x23 0x3C 0x57
[BH1750] online
[Sonar] online at 0x57
[OLED] online
[SmartCane] ready
```

实际 I2C 地址取决于模块接线，其中 BH1750 可能是 `0x23` 或 `0x5C`。

## 7. 主循环与非阻塞调度

```mermaid
flowchart LR
    A["network.update"] --> B["更新 IMU / GPS / 超声波 / 光照"]
    B --> C["刷新 OLED"]
    C --> D["发布网页状态快照"]
    D --> E["输出周期日志"]
    E --> F["delay(1) 让出调度"]
    F --> A
```

工程避免用长时间 `delay()` 等待设备：

- 超声波发送测距命令后进入 `Waiting` 状态，按实测 Demo 在 130 ms 后读取；
- 光照、显示和超声波分别由毫秒时间戳控制周期；
- UART 驱动每轮只消费当前已到达的字节；
- Wi-Fi 连接超时由状态机判断，不阻塞其他传感器；
- 主循环末尾只有 `delay(1)`，用于让 Arduino/网络服务保持基本运行；双核 FreeRTOS 任务划分暂未实现。

## 8. 数据流与并发预留

### 8.1 传感器数据通道

```text
硬件字节/测量值
  → drivers 解析和校验
  → SensorSnapshot 保存最近有效数据
  → OLED、串口和网页读取结果
```

数据都带有效标志和更新时间。超过 `SENSOR_STALE_MS` 或 `GPS_STALE_MS` 后会被标记为无效，避免使用已经断线的旧数据继续触发判断。

### 8.2 网页命令

网页命令入口仍保留，用于保持接口兼容；当前命令回调只有中文 TODO，不执行 SOS、告警或照明控制。

### 8.3 主循环到网页

主循环把传感器、告警占位值、输出和网络状态复制到 `PublishedState`。双核 FreeRTOS 下的并发保护暂未实现，代码中保留 TODO。

## 9. 关键业务逻辑

### 9.1 跌倒检测与分级告警

当前不设距离、照度、加速度、冲击、倾角或告警节奏参数。`FallDetector` 和
`AlarmController` 只保留接口，具体实现留待后续方案确认。

<!-- TODO：补充正式的跌倒检测、分级告警、锁存和执行器策略说明。 -->

## 10. 硬件接口

| 总线/信号 | 模块 | ESP32-S3 引脚 | 参数 |
|---|---|---:|---|
| I2C SDA/SCL | HC-SR04 IIC、BH1750、SSD1306 | GPIO41 / GPIO42 | 100 kHz |
| UART1 RX/TX | JY901S | GPIO39 / GPIO38 | 9600, 8N1 |
| UART2 RX/TX | ATGM336H | GPIO47 / GPIO21 | 9600, 8N1 |
| 数字输入 | SOS 按键 | GPIO40 | 高电平按下，内部下拉 |
| 数字输出 | 蜂鸣器 MOS 栅极 | GPIO1 | 高电平开启 |
| 数字输出 | 照明 LED | GPIO14 | 高电平开启 |

相机固定使用 SCCB GPIO4/5、VSYNC 6、HREF 7、XCLK 15、PCLK 13、数据 GPIO8/9/10/11/12/16/17/18。`BoardConfig.h` 中的静态断言会阻止外围 I2C SDA 与相机 SCCB SDA 被配置成同一引脚。

## 11. 网络与摄像头服务

### 11.1 联网状态机

1. `WIFI_SSID` 留空：直接建立热点；
2. 已填写 SSID：先尝试连接路由器；
3. 12 秒内连接失败：回退热点；
4. 路由器模式运行中断线超过 12 秒：回退热点。

默认热点：

- SSID：`SmartCane-Camera`
- 密码：`12345678`
- 地址：`http://192.168.4.1/`

### 11.2 摄像头策略

- 找到 PSRAM：VGA、JPEG 质量 12、双帧缓冲、帧缓冲放在 PSRAM；
- 未找到 PSRAM：QVGA、JPEG 质量 15、单帧缓冲、帧缓冲放在片内 RAM；
- 抓取模式为 `CAMERA_GRAB_LATEST`，优先返回最新画面。

### 11.3 HTTP 接口

| 地址 | 方法 | 端口 | 功能 |
|---|---|---:|---|
| `/` | GET | 80 | 内置中文监控页面 |
| `/api/status` | GET | 80 | 返回系统 JSON 快照 |
| `/capture` | GET | 80 | 返回单张 JPEG |
| `/api/sos` | POST | 80 | 触发 SOS |
| `/api/cancel` | POST | 80 | 告警解除接口占位，当前不改变状态 |
| `/api/light?mode=on/off/auto` | GET | 80 | 设置照明模式 |
| `/stream` | GET | 81 | MJPEG 视频流 |

视频流单独占用 81 端口，避免持续连接阻塞普通网页/API 请求。

## 12. 每一个文件的作用

### 12.1 根目录和 VS Code 配置

| 文件 | 类型 | 作用与维护说明 |
|---|---|---|
| `.gitignore` | 手写配置 | 忽略 PlatformIO 构建目录以及自动生成的 IntelliSense、调试数据库和临时文件。不要把这些机器相关文件提交到版本库。 |
| `platformio.ini` | 核心手写配置 | 定义 ESP32-S3-CAM 构建环境、8 MB Flash、OPI PSRAM、分区、串口速度、宏和中文路径规避方案。更换板型、框架或构建选项时首先检查此文件。 |
| `README.md` | 项目首页 | 提供功能、接线、首次配置、网页接口和实机测试顺序的快速说明。适合新成员先阅读。 |
| `SmartCane.ino` | Arduino IDE 入口 | Arduino IDE 使用的 `setup()/loop()`。PlatformIO 构建时由宏和过滤器排除，避免与 `src/main.cpp` 冲突。 |
| `.vscode/extensions.json` | 推荐扩展配置 | 建议安装 PlatformIO IDE，并避免重复推荐完整 C/C++ 扩展包。 |
| `.vscode/settings.json` | 工作区设置 | 当前只保留 STM32 扩展的 OpenOCD 路径开关，对 SmartCane 运行逻辑没有影响。 |
| `.vscode/c_cpp_properties.json` | 自动生成 | PlatformIO 生成的头文件搜索路径、宏、标准和 Xtensa 编译器路径，为代码补全服务。文件头明确要求不要手改；修改 `platformio.ini` 后由 PlatformIO 重建。 |
| `.vscode/launch.json` | 自动生成 | PlatformIO 生成的断点调试配置，指向临时目录中的 `firmware.elf` 和 Xtensa 工具链。换电脑或重新生成项目时路径会变化，不应作为业务配置维护。 |
| `docs/01-工程架构与文件说明.md` | 维护文档 | 本文档，记录总体架构、运行流程、数据流、关键逻辑和逐文件职责。架构发生变化时应同步更新。 |
| `docs/02-ESP32-Arduino开发与调试指南.md` | 使用文档 | 面向初学者的环境、编译、烧录、串口、分阶段硬件测试和故障排查指南。开发流程或板卡操作变化时应同步更新。 |

### 12.2 入口与应用层

| 文件 | 作用 |
|---|---|
| `src/main.cpp` | PlatformIO 入口。仅在定义 `SMARTCANE_PLATFORMIO` 时提供 `setup()/loop()`，把所有工作交给 `SmartCaneApp`。文件头注释存在历史编码乱码，但不影响编译。 |
| `src/app/SmartCaneApp.h` | 声明系统总协调类、模块成员、发布状态和周期时间戳；双核 FreeRTOS 队列/互斥量暂只留 TODO。 |
| `src/app/SmartCaneApp.cpp` | 实现开机初始化、I2C 扫描、非阻塞主循环、数据过期处理、OLED 刷新、JSON 组装、状态快照和串口日志；跌倒、告警和任务化逻辑暂留 TODO。 |

### 12.3 配置与数据模型

| 文件 | 作用 |
|---|---|
| `src/config/BoardConfig.h` | 板级固定配置：GPIO、UART/I2C 波特率、OV2640 引脚。只在硬件接线或板型变化时修改。 |
| `src/config/UserConfig.h` | 用户可调配置：Wi-Fi、热点、图像翻转、I2C 地址、采样周期和数据过期时间；跌倒/告警参数暂未定义。 |
| `src/model/SystemState.h` | 定义 `ImuReading`、`GpsReading`、`SensorSnapshot`、`AlarmKind` 和告警英文名；是驱动、控制、显示和网页之间的共享数据契约。 |

### 12.4 控制层

| 文件 | 作用 |
|---|---|
| `src/control/AlarmController.h` | 声明分级告警状态机的空接口。 |
| `src/control/AlarmController.cpp` | 当前只保留中文 TODO，不执行告警、锁存、蜂鸣或照明控制。 |
| `src/control/FallDetector.h` | 声明跌倒检测空接口。 |
| `src/control/FallDetector.cpp` | 当前只保留中文 TODO，不执行阈值判断或事件检测。 |

### 12.5 驱动层

| 文件 | 作用 |
|---|---|
| `src/drivers/Atgm336h.h` | 声明 GPS 串口接收、NMEA 行缓存、RMC/GGA 解析、校验和、坐标换算和在线判断接口。 |
| `src/drivers/Atgm336h.cpp` | 逐字节收集 NMEA 语句，校验 `*XX`，解析 UTC、定位有效性、经纬度、速度、海拔和卫星数。 |
| `src/drivers/Bh1750.h` | 声明 BH1750 I2C 初始化、照度读取和地址查询接口。 |
| `src/drivers/Bh1750.cpp` | 自动探测 `0x23/0x5C`，进入连续高分辨率模式，并按 `raw / 1.2` 换算 lux。通信失败时会重新初始化。 |
| `src/drivers/DebouncedButton.h` | 声明通用按键消抖、按下/释放事件和长按时长接口。 |
| `src/drivers/DebouncedButton.cpp` | 使用 30 ms 稳定时间过滤机械抖动；SOS 键采用高电平有效和内部下拉。 |
| `src/drivers/DigitalOutputs.h` | 声明蜂鸣器和照明 LED 的统一开关接口，并保存当前输出状态。 |
| `src/drivers/DigitalOutputs.cpp` | 初始化 GPIO，按高/低有效配置写入电平，保证上电时两个输出都关闭。 |
| `src/drivers/Hcsr04I2c.h` | 声明 2021 IIC 版 HC-SR04 的非阻塞测距状态机和新数据提取接口。 |
| `src/drivers/Hcsr04I2c.cpp` | 写 `0x01` 启动测距，130 ms 后读取 3 字节微米值，换算厘米并过滤 0、全 1 和 2–500 cm 之外的异常值。 |
| `src/drivers/Jy901s.h` | 声明 JY901S 11 字节帧接收、校验、解码和在线判断接口。 |
| `src/drivers/Jy901s.cpp` | 同步 `0x55` 帧头，解析 `0x51/0x52/0x53` 加速度、角速度和欧拉角帧；收到姿态帧后发布一组完整 IMU 数据。 |
| `src/drivers/Ssd1306.h` | 声明 SSD1306 初始化、清屏、字符绘制、像素操作和整帧刷新接口。 |
| `src/drivers/Ssd1306.cpp` | 内置精简 5×7 英数字体和 1024 字节帧缓冲，不依赖第三方 OLED 库；通过 I2C 分块发送显示数据。 |

### 12.6 服务层

| 文件 | 作用 |
|---|---|
| `src/services/WifiCameraServer.h` | 声明 Wi-Fi 状态机、摄像头、HTTP 双服务器、状态提供回调和命令回调接口。 |
| `src/services/WifiCameraServer.cpp` | 实现路由器/热点切换、OV2640 初始化、内置网页、JSON 状态、单张抓拍、MJPEG 视频流及 SOS/取消/照明 API。 |

## 13. 配置修改边界

### 只改参数，不改逻辑

优先修改 `UserConfig.h`：

- Wi-Fi 名称和密码；
- 相机翻转；
- 传感器地址；
- 采样间隔；
- 数据过期时间。

### 改了硬件接线

修改 `BoardConfig.h`，同时核对：

- 新引脚是否被相机占用；
- 输入是否需要上拉或下拉；
- 外设电平是否为 3.3 V；
- UART 的 RX/TX 是否交叉连接。

### 更换传感器型号或协议

在 `drivers/` 中新增或替换驱动，并尽量保持输出到 `SystemState.h` 的数据结构不变。这样显示、告警和网页层通常不需要改。

### 修改业务规则

- 跌倒检测（待实现）：`FallDetector.*`；
- 告警状态机（待实现）：`AlarmController.*`；
- 调度顺序或新模块集成：`SmartCaneApp.*`；
- 网页、API 或相机：`WifiCameraServer.*`。

## 14. 已知设计限制

- 跌倒算法使用固定阈值，尚未根据真实用户数据标定，不能作为医疗或人身安全认证结论；
- 持续倾斜检测无法区分“人跌倒”和“拐杖靠墙”，建议后续加入握持/压力信息；
- 网页没有身份认证，热点密码和路由器内网是当前访问边界；
- Wi-Fi 密码以明文编译进固件，不应把真实密码提交到公开仓库；
- HTTP 命令队列使用零等待发送，极端高频请求可能丢弃命令；
- OLED 字体只覆盖常用英文字母、数字和少量符号，不支持中文；
- 摄像头分辨率依赖 `psramFound()`，PSRAM 配置或供电异常会自动降级或导致相机初始化失败。

## 15. 建议阅读顺序

第一次阅读源码时，按以下顺序最容易建立整体认识：

1. `platformio.ini`：确认目标板和构建方式；
2. `src/config/BoardConfig.h`、`UserConfig.h`：理解硬件与参数；
3. `src/model/SystemState.h`：理解模块交换的数据；
4. `src/main.cpp`、`SmartCaneApp.*`：理解启动和主循环；
5. `FallDetector.*`、`AlarmController.*`：理解业务决策；
6. 逐个阅读 `drivers/`：理解各设备协议；
7. `WifiCameraServer.*`：理解并发、网页和视频流。

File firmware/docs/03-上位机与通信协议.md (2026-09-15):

# 上位机与 SC1 通信协议

## 1. 链路划分

| 链路 | 端点 | 用途 |
|---|---|---|
| CH340 UART0 | 115200, 8N1 | 5 Hz 传感器/状态遥测与双向控制 |
| HTTP 80 | `/capture`、`/api/status` | 抓拍、调试和浏览器兼容接口 |
| MJPEG 81 | `/stream` | 上位机实时图传 |
| 在线地图 | 按当前视口加载 OSM 瓦片 | GPS 底图；有缓存且不做预下载 |

传感器数据固定走串口，图像固定走 Wi-Fi。两条链路断开时互不影响，上位机分别显示状态。

## 2. 串口帧

每帧以换行结束，协议帧固定以 `SC1 ` 开头。设备的人工启动日志不带此前缀，上位机会忽略或放入日志区。

```text
SC1 HELLO {"protocol":"smartcane.serial","version":1,"baud":115200}
SC1 TEL {"protocol":"smartcane.telemetry","version":1,...}
SC1 ACK PING
SC1 ERR unknown_command
```

跌倒标定时可临时开启“每个新 JY901S 样本一行”的紧凑 CSV 数据流：

```text
SC1 CMD IMU STREAM ON
SC1 IMU HEADER seq,t_ms,ax_g,...,fall_latched
SC1 IMU 1,12345,0.0100,...,NORMAL,0,0
SC1 CMD IMU STREAM OFF
```

`seq` 在设备端按新样本递增，上位机利用序号间隙计算串口/队列丢帧；`t_ms`
是该组姿态帧到达 ESP32 的时间。CSV 同时给出原始九轴、`a_g`、`g_dps`、
`tilt_deg`、跌倒候选阶段和阈值布尔量。数据流关闭时不产生额外高频输出。

遥测 JSON 字段：

- 系统：`uptime_ms`、`alarm`、`buzzer`、`light`、`sos_latched`、`fall_latched`；
- 测距/光照：`distance_cm`、`lux`，无效值为 JSON `null`；
- IMU：`valid`、三轴 `ax/ay/az_g`、三轴 `gyro_*_dps`、`roll/pitch/yaw_deg`、`accel_g`；
- GPS：`gps` 为当前定位的 `valid`、`lat`、`lon`、`speed_kmh`、`altitude_m`、`satellites`、`utc`；`last_fix` 为本次上电以来最后一次有效定位，含 `available`、经纬度、卫星数、UTC 和 `age_ms`。当前失星时 `gps.valid=false`，但 `last_fix` 会保留供网页显示最后位置；断电重启后会清空。
- 网络/相机：`ip`、`ap_mode`、`rssi`、`camera`。

## 3. 上位机命令

```text
SC1 CMD PING
SC1 CMD GET
SC1 CMD SOS
SC1 CMD CANCEL
SC1 CMD LIGHT AUTO
SC1 CMD LIGHT ON
SC1 CMD LIGHT OFF
SC1 CMD IMU STREAM ON
SC1 CMD IMU STREAM OFF
```

设备只接受上述白名单命令。`GET` 立即发一帧遥测；其他有效命令先进入已有命令队列，再由主循环处理。

## 4. 地图与坐标

GPS 与导入文件统一按 WGS-84 的 `纬度, 经度` 显示。GeoJSON 内部仍遵循标准的 `[经度, 纬度]` 顺序。上位机使用 Web Mercator 绘制在线瓦片、实时轨迹和导入矢量；GPX、KML 会先转换成内存中的 GeoJSON。

底图只请求用户当前看到的瓦片并尊重 HTTP 缓存。ESP32 独立热点没有互联网时，底图请求会失败，但暗色坐标网格、GPS点及导入/实时轨迹继续工作。

## 5. 上位机职责边界

跌倒检测与状态机仍完全运行在 ESP32 上。Qt 只记录固件给出的原始量、派生量和
判定过程，不在电脑端替代实时报警。后续离线网页可以重放 CSV 并比较候选阈值，
但修改后的阈值必须重新编译烧录，再通过独立实机数据验证。

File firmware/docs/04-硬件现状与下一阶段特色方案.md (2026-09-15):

# 智能拐杖硬件现状与下一阶段特色方案

> 方案名称：**“安迹 SafeTrace”——自适应避障、二阶段异常确认与事件证据包智能拐杖**  
> 编写依据：当前 `SmartCane` 代码、已完成的单模块 Demo、现有上位机和项目初步计划。  
> 方案原则：优先用好现有 ESP32-S3-CAM，不把新增 STM32、电机、云台、4G 或心率血氧作为主线成立的前提。

## 1. 结论先行

当前硬件已经足够完成一个结构完整的智能拐杖原型，没有必要为了“看起来复杂”立即增加 STM32。现阶段最值得投入的方向不是继续堆模块，而是把已有的超声波、IMU、GPS、摄像头、光照和 SOS 按键组织成一套可靠、可解释、能远程确认的安全流程。

建议把项目定位从常见的“测到障碍就响、拐杖倒了就报警”，提升为：

> **平时根据距离变化和使用状态进行低干扰避障；出现疑似跌倒或 SOS 时先进行本地确认，随后把触发原因、传感器时间线、最后有效位置和现场图片组合为一个事件证据包，交给家属判断。**

这条主线同时保留了课程设计需要的基本功能，又有四个能真正讲清楚的特色：

1. 避障由固定距离阈值升级为“距离 + 接近速度 + 数据可信度”的自适应风险；
2. 跌倒不直接等于报警，而是经过疑似异常、用户确认窗口和最终告警；
3. 摄像头不是持续监控，而是异常触发、按需取证，兼顾隐私和资源；
4. 远程端收到的不只是一个 `FALL` 字符串，而是一份包含原因、位置、图像和时间线的可解释事件。

## 2. 当前硬件和代码的真实情况

### 2.1 已由代码和 Demo 确认的硬件

| 模块 | 当前实际型号/资源 | 接口与引脚 | 当前代码能力 | 后续可直接利用的数据 |
|---|---|---|---|---|
| 主控 | GOOUUU ESP32-S3-CAM | 双核 ESP32-S3，工程配置为 8 MB Flash、OPI PSRAM | Arduino/PlatformIO、Wi-Fi、HTTP、FreeRTOS基础同步 | 系统调度、网络、算法和图传 |
| 摄像头 | OV2640 | 固定并行相机总线，GPIO4～18中的多个引脚已占用 | VGA/QVGA JPEG、单张抓拍、MJPEG流 | 异常现场图像、远程查看 |
| 前向测距 | HC-SR04 2021 UART/IIC版 | I2C `0x57`，GPIO41/42 | 非阻塞触发，130 ms后读取，过滤2～500 cm异常值 | 距离、距离变化率、接近时间 |
| IMU | **JY901S**，不是计划表中的MPU6050 | UART1，RX39/TX38，9600 bit/s | 加速度、角速度、欧拉角，0x55帧校验 | 运动强度、冲击、倾角、静止程度 |
| GNSS | ATGM336H | UART2，RX47/TX21，9600 bit/s | 校验并解析RMC/GGA | 经纬度、速度、海拔、卫星数、UTC |
| 光照 | BH1750/GY-302 | I2C `0x23`或`0x5C` | 连续高分辨率照度读取 | 环境照度、夜间模式依据 |
| OLED | SSD1306 128×64 | I2C `0x3C` | 显示告警、距离、照度、GPS和IP | 本地状态与故障提示 |
| 求助输入 | SOS按键 | GPIO40，高电平按下 | 按下触发；锁存告警时再次按下解除 | 主动求助、异常取消/确认 |
| 本地输出 | 有源蜂鸣器 | GPIO1，经MOS驱动 | 多种非阻塞蜂鸣节奏 | 避障、确认提示、紧急报警 |
| 照明输出 | LED/照明灯 | GPIO14 | 自动/手动开关、告警闪烁 | 夜间照明、异常示警 |
| 电脑上位机 | Python + PyQt5 | CH340串口 + Wi-Fi | 传感器显示、命令、MJPEG、GPS地图、轨迹导入 | 联调、展示和看护端原型 |

### 2.2 当前已经打通的软件链路

```text
传感器驱动
  → SensorSnapshot统一快照
  → 参考告警/跌倒接口
  → OLED、蜂鸣器、照明
  → SC1串口JSON / HTTP状态
  → Windows上位机、摄像头图传和GPS地图
```

当前各接口已经能独立工作，但以下部分仍属于后续开发：

- 正式的FreeRTOS任务划分；
- 传感器滤波、特征提取和融合；
- 经数据标定的跌倒算法；
- 产品级主状态机；
- 互联网远程通知和事件存储。

### 2.3 计划中出现、但当前代码不能证明已经具备的硬件

| 项目 | 当前判断 | 对方案的处理 |
|---|---|---|
| 震动马达 | `BoardConfig.h`中没有控制引脚和驱动 | 不写成已实现功能；以后可由MOS管增加一个GPIO输出 |
| 电池电压检测 | 没有ADC分压引脚和采样代码 | 暂不设计“低电量状态”，除非先补硬件采样回路 |
| 心率/血氧 | 没有对应传感器和驱动 | 作为增强项，不进入主线验收 |
| 摄像头云台 | 没有舵机、电机驱动和已验证空闲引脚 | 不作为当前方案组成，不为它新增STM32 |
| 4G Cat.1 | 没有模块、供电、串口和通信栈 | 只保留未来“事件小包上传”，不承诺4G实时图传 |
| SD卡/大容量存储 | 当前代码没有SD接口 | 图片不长期写Flash；事件应尽快上传，离线只短期保存在PSRAM |
| 独立STM32 | 当前没有必要 | 只有确实增加多电机闭环控制后才重新评估 |

### 2.4 当前配置与原计划的差异

1. 原计划写MPU6050，实物和驱动实际为JY901S；报告、PPT和原理图应统一改为JY901S。
2. 原计划写震动马达联动，当前代码只有蜂鸣器和LED，不能把震动写成已完成。
3. 原计划目标超声波刷新率不低于5 Hz，当前间隔为220 ms，约4.5 Hz；若实测稳定，可调整至200 ms。
4. 原计划要求跌倒后2 s内报警，当前参考流程的冲击后确认时间为2.5 s，正式算法需要重新设计和验收。
5. 当前工程配置为8 MB Flash和OPI PSRAM，计划采购描述中出现N16R8；必须读取实机Flash/PSRAM容量后再在材料中写死型号。

## 3. 现有硬件的能力边界

### 3.1 为什么现在不需要增加STM32

ESP32-S3本身是双核处理器，ESP-IDF FreeRTOS提供任务绑核接口，足够把传感器/决策与网络图传分开调度。当前控制对象只有蜂鸣器、照明和按键，没有多路高速电机闭环、编码器采样或严格微秒级控制，因此增加第二颗MCU只会新增通信协议、供电、PCB和联调成本。

官方资料也确认ESP32-S3支持双核和FreeRTOS任务绑核；相机驱动原生支持ESP32-S3与OV2640。工程应先用队列、快照和任务优先级解决资源竞争，而不是先用第二颗MCU回避软件架构问题。

只有同时满足以下条件时，才值得重新考虑STM32：

- 新增两个以上电机/舵机并要求稳定闭环；
- 需要编码器、FOC或高频PWM采样；
- 图传压力下ESP32-S3无法满足已量化的控制截止时间；
- 已完成任务运行时间、栈余量和CPU占用测试，确认瓶颈确实来自算力而非阻塞代码。

### 3.2 必须承认的限制

- 单个前向超声波只知道一个方向的距离，不能可靠识别坑洞、台阶边缘、侧面障碍或障碍物类别。
- IMU装在拐杖上，测到的是“拐杖运动”，不是人体本身；拐杖靠墙、掉落或剧烈挥动都可能像跌倒。
- GPS主要适合室外；室内无定位时只能提供最后一次有效位置，不能伪造当前位置。
- Wi-Fi AP模式只能实现设备附近的本地看护；真正跨互联网远程看护需要设备接入路由器或手机热点，并连接服务器。
- 摄像头和Wi-Fi对供电及PSRAM敏感。Espressif相机驱动说明指出，除CIF及以下JPEG等情况外通常需要启用PSRAM；高分辨率、双帧缓冲会增加CPU和内存压力。
- 没有SD卡时不能把大量JPEG长期写入本地；频繁写内部Flash还会带来寿命和阻塞风险。

这些限制不是项目失败点。恰当的创新是“在限制内做可靠决策”，而不是把一个前向摄像头包装成全场景自动驾驶。

## 4. 建议确定的产品方案

### 4.1 方案名称与一句话介绍

**安迹 SafeTrace：面向独立出行的事件驱动型智能看护拐杖。**

> 它平时根据障碍接近风险进行低干扰提醒；异常时通过IMU、用户反馈、GPS和摄像头进行二阶段确认，并生成可解释的远程事件证据包。

### 4.2 基本功能层：保证它首先是一根“好用的智能拐杖”

| 基本功能 | 实现方式 | 当前基础 | 下一步工作 |
|---|---|---|---|
| 前向避障 | 超声波距离、滤波、分级蜂鸣 | 驱动和参考阈值已有 | 增加中值滤波、滞回和动态风险 |
| 夜间照明 | BH1750低照度自动开灯 | 已打通 | 增加滞回，避免临界照度闪烁 |
| 主动SOS | 按键立即锁存求助 | 已打通 | 加入事件包和远程确认 |
| 本地异常报警 | 蜂鸣器、LED节奏 | 已打通 | 由正式状态机统一输出 |
| GPS位置 | ATGM336H定位、地图显示 | 已打通 | 保存最后有效位置和定位质量 |
| 现场图像 | OV2640抓拍/MJPEG | 已打通 | 改为正常低负载、异常按需抓拍/图传 |
| 本地/电脑显示 | OLED、上位机 | 已打通 | 增加事件时间线和健康状态 |

### 4.3 核心创新一：自适应避障风险，而不是只有固定距离

常见项目只判断“距离是否小于50 cm”。本方案在不增加硬件的情况下，增加距离趋势：

```text
接近速度 v_close = max(0, (上次距离 - 当前距离) / 时间差)
预计碰撞时间 TTC = 当前距离 / v_close
```

风险判断同时使用：

- 当前距离；
- 障碍物是否正在快速接近；
- 最近若干次测距是否稳定；
- IMU判断当前是静止、正常行走还是剧烈晃动；
- GPS速度只作为室外低权重参考，不作为近距离避障主依据。

效果示例：

- 站着不动、障碍在80 cm处：只进行低频提示；
- 正向快速接近、障碍仍有120 cm：因为TTC变小，可以提前提醒；
- 测距连续无效：不输出虚假“安全”，而是提示避障传感器不可用。

这比增加第二个蜂鸣器或多写几个固定阈值更有实际意义，也能形成清晰的算法对比实验。

### 4.4 核心创新二：二阶段异常确认，降低跌倒误报

当前拐杖IMU无法直接证明“人跌倒”，因此状态机不应从一次冲击直接跳到远程报警。建议流程：

```mermaid
stateDiagram-v2
    [*] --> Normal
    Normal --> Suspected: 冲击/倾角/运动模式异常
    Suspected --> Normal: 后续运动恢复正常
    Suspected --> ConfirmWindow: 异常持续并满足组合条件
    ConfirmWindow --> Cancelled: 用户再次按下SOS取消
    ConfirmWindow --> Emergency: 超时未取消
    Normal --> Emergency: 用户主动按下SOS
    Emergency --> Reporting: 生成并上传事件证据包
    Reporting --> Emergency: 等待远程确认/本地解除
    Cancelled --> Normal
```

建议的异常判断输入：

- 加速度模长及峰值；
- 三轴角速度峰值；
- 横滚/俯仰角和持续时间；
- 冲击后的低运动方差或长时间静止；
- 拐杖是否很快恢复正常姿态；
- 用户是否在确认窗口内取消。

建议把“拐杖慢慢靠墙”作为必须加入数据集的负样本，而不是继续调一个万能倾角阈值。

### 4.5 核心创新三：异常事件证据包

确认SOS或异常后，不只发送“跌倒了”，而是生成一个 `CareEvent`：

| 内容 | 建议字段/形式 | 价值 |
|---|---|---|
| 事件身份 | `event_id`、类型、设备运行时间、UTC | 区分重复报警和重连 |
| 可解释原因 | 冲击峰值、倾角、静止时长、用户是否取消 | 家属知道为什么报警 |
| 传感器时间线 | 事件前10 s、后20 s的低频特征 | 复盘误报、后续改算法 |
| 位置 | 当前或最后有效经纬度、卫星数、定位年龄 | 不把无效GPS当真位置 |
| 现场图像 | 1～3张JPEG；必要时再开启MJPEG | 减少带宽并保护隐私 |
| 设备健康 | IMU、超声波、GPS、相机在线状态 | 区分“异常”与“设备坏了” |

实现建议：

- 传感器特征使用固定长度环形缓冲，优先放在内部RAM；
- PSRAM充足时可保留少量低频JPEG，PSRAM不足则只在事件发生时抓拍；
- 事件元数据可低频写NVS，图片不要反复写内部Flash；
- 上传失败时在PSRAM保留最近一份事件，恢复网络后重试；设备掉电后图片丢失属于当前无SD卡方案的明确限制。

### 4.6 核心创新四：隐私友好的按需图传

普通“摄像头拐杖”往往默认持续直播。本方案建议：

- 正常状态：不开远程上传，或只提供用户主动访问的低帧率本地画面；
- 疑似异常：抓拍一张供状态机记录，不立即对外持续推流；
- 确认异常/SOS：上传事件图片，并允许看护端主动打开实时流；
- 告警解除：停止异常推流，回到低负载模式。

这样既降低相机和Wi-Fi对主循环的压力，也能把“隐私保护”写成真实的系统设计，而不是宣传词。

### 4.7 工程特色：健康自检和降级运行

真正可靠的产品不只显示数值，还要知道数据是否可信。当前代码已经有 `valid` 和数据超时基础，可以继续形成：

- 超声波失效：关闭基于距离的自动判断，明确提示“避障不可用”；
- IMU失效：保留SOS和避障，关闭自动跌倒判断；
- GPS无定位：上传最后有效位置及其时间，不显示伪坐标；
- 相机失效：事件仍发送传感器和位置，不让图像失败阻塞本地报警；
- Wi-Fi断开：本地避障、照明和告警继续运行，网络恢复后重报事件。

“故障时仍保留部分能力”比简单显示一个 `offline` 更有工程价值，也适合在答辩中演示拔掉某个模块后的系统行为。

## 5. 不增加STM32的FreeRTOS架构建议

### 5.1 任务划分

| 任务 | 建议周期/触发 | 建议优先级 | 建议核心 | 职责 |
|---|---|---:|---|---|
| `SensorTask` | 5～10 ms轮询，设备按各自周期采样 | 5 | Core 1 | 消费IMU/GPS串口、调度超声波和光照、生成原始快照 |
| `DecisionTask` | 20～50 ms | 4 | Core 1 | 滤波、特征、自适应避障、异常检测和主状态机 |
| `ActuatorTask` | 10～20 ms | 3 | Core 1 | 根据唯一控制指令更新蜂鸣器和LED，不自行判断状态 |
| `EventTask` | 队列事件触发 | 3 | 不先强制绑核 | 组装CareEvent、触发抓拍、安排重试 |
| `TelemetryTask` | 200 ms | 2 | Core 0或不绑核 | 串口/HTTP状态快照发布 |
| 摄像头/HTTP | 请求或事件触发 | 使用驱动任务 | 先沿用框架默认 | MJPEG、抓拍和网页请求 |

不建议一开始把所有网络和相机代码都手工钉死在Core 0。ESP-IDF自身已有Wi-Fi、事件循环和HTTP相关任务；应先固定传感器与决策在Core 1，测量任务运行时间和看门狗情况，再决定是否进一步绑核。

### 5.2 任务间只传数据，不互相操作硬件

建议使用三类通道：

```text
SensorSnapshotQueue（长度1，覆盖旧值）
  SensorTask → DecisionTask

ControlCommandQueue
  DecisionTask → ActuatorTask

CareEventQueue
  DecisionTask/SOS → EventTask → Camera/Network
```

基本规则：

- 只有 `SensorTask` 访问传感器驱动；
- 只有 `ActuatorTask` 写蜂鸣器和LED；
- `DecisionTask` 只读快照、输出状态和命令；
- HTTP回调只入队，不直接修改状态机；
- 上位机读取的是发布快照，不读取正在变化的内部对象。

主控制入口仍放在 `src/app/SmartCaneApp.cpp`，任务句柄和队列声明放在 `SmartCaneApp.h`；算法较大后再拆到 `src/algorithm/`，状态机拆到 `src/control/SystemStateMachine.*`。

## 6. 状态机应避免“状态爆炸”

原计划把夜间、避障、跌倒、SOS、低电量都列为主状态，但它们可以同时发生。例如夜间也可能遇到障碍，Wi-Fi断开时也可能SOS。建议拆成三组正交状态：

### 6.1 安全主状态

```text
NORMAL
OBSTACLE_CAUTION
OBSTACLE_DANGER
SUSPECTED_FALL
CONFIRM_WINDOW
EMERGENCY
```

### 6.2 独立模式

- `LightMode`：AUTO / ON / OFF；
- `NetworkState`：OFFLINE / AP / STA_LOCAL / INTERNET_READY；
- `HealthFlags`：SONAR、IMU、GPS、CAMERA等在线位；
- `GpsState`：NO_DATA / NO_FIX / FIX / STALE_FIX。

这样 `EMERGENCY + OFFLINE + AUTO_LIGHT` 可以同时存在，不需要为每种组合再创造一个枚举状态。

## 7. 算法实施建议

### 7.1 先做可解释特征，不急着上神经网络

建议先保存带标签的JY901S数据：正常行走、上下楼、快速挥动、拐杖掉落、靠墙、坐下、模拟跌倒。每个滑动窗口提取：

- 加速度模长均值、方差、最大值、最小值；
- 三轴角速度峰值和能量；
- 横滚/俯仰变化量和持续倾角；
- 冲击前后静止程度；
- 事件持续时间。

第一版使用规则、逻辑回归、小型决策树或随机森林离线训练后导出常量，比直接在摄像头上跑大模型更容易形成可靠结果和对比实验。

### 7.2 TinyML作为后期加分项，不作为主线前置条件

ESP32-S3具有面向AI/DSP的向量指令，Espressif也提供ESP-DL推理库，因此后期可以尝试小型量化模型。但ESP-DL官方流程主要基于ESP-IDF，当前工程使用Arduino框架；迁移成本、模型转换、PSRAM和相机资源竞争都需要单独评估。

推荐优先级：

1. 先完成可解释规则和数据集；
2. 用相同测试集比较规则与轻量分类器；
3. 只有离线模型明显更好，再考虑量化部署；
4. 暂不承诺仅靠现有单摄像头完成坑洞/楼梯/盲道识别。

## 8. 远程看护的可落地路径

### 8.1 当前即可完成：近距离或同局域网看护

- ESP32建立AP，手机/电脑连接设备热点；
- 或ESP32和看护端连接同一路由器；
- 浏览器/上位机查看状态、地图和MJPEG；
- 异常时在本地网络内自动显示事件。

### 8.2 不增加硬件的实用升级：手机热点作为网关

让ESP32以STA模式连接使用者手机热点，事件通过HTTPS/MQTT发送到轻量服务器，看护者通过手机网页接收通知。这样不需要4G模块，但必须明确：

- 使用者手机需要开热点并有互联网；
- ESP32需要配置热点凭据；
- 服务器只传事件元数据和少量JPEG，实时视频按需打开；
- 网络不可用时，本地安全功能必须照常工作。

### 8.3 未来4G扩展

如果后期确实需要脱离手机独立联网，4G Cat.1只负责：

- SOS/异常事件JSON；
- GPS位置；
- 1张压缩JPEG或图片下载地址。

不建议把4G实时视频作为课程设计硬指标，它会显著增加功耗、资费、天线、供电和网络调试风险。

## 9. 分阶段实施路线

### 阶段0：冻结并核实硬件

- 实机输出Flash容量、PSRAM容量和剩余堆；
- 确认摄像头开启时5 V电源无复位；
- 统一报告中的JY901S型号；
- 明确震动马达、电池检测和4G均不在当前验收范围。

### 阶段1：完成可靠的基本功能

- 建立FreeRTOS任务、队列和唯一硬件访问者；
- 超声波中值滤波、滞回和传感器超时；
- 完成本地避障、夜间照明、SOS、GPS和图传；
- 网络断开时验证本地功能不受影响。

### 阶段2：实现SafeTrace核心主线

- 加入距离变化率/TTC风险；
- 实现疑似跌倒、确认窗口、取消和紧急状态；
- 建立传感器特征环形缓冲；
- 生成包含原因、位置、健康状态和JPEG的CareEvent；
- 上位机增加事件时间线和确认页面。

### 阶段3：完成远程看护演示

- ESP32连接路由器或手机热点；
- 事件JSON和JPEG上传；
- 看护端展示事件、地图、图片及实时流入口；
- 完成断网重试和重复事件去重。

### 阶段4：有余力再做的增强

- 基于真实数据训练轻量IMU分类器；
- 加入震动马达，但仍由ESP32直接控制；
- 评估心率血氧是否真的改善异常判断；
- 只有明确需要多电机闭环时才研究云台和第二MCU。

## 10. 建议验收指标

以下为下一阶段建议指标，不代表当前代码已经达到：

| 类别 | 建议验收方法 | 建议目标 |
|---|---|---|
| 避障刷新 | 连续记录有效距离时间戳 | 稳定不低于5 Hz |
| 避障响应 | 障碍进入危险区到本地提醒 | 小于300 ms |
| 图传干扰 | 同时开启VGA/QVGA图传并记录传感器间隔 | 传感器不连续超时，控制不被阻塞 |
| 异常响应 | 冲击/倾倒到进入确认窗口 | 小于1 s |
| 最终求助 | 确认窗口超时或主动SOS到本地紧急报警 | 小于200 ms |
| 跌倒误报 | 正常行走30 min、靠墙/放下各50次 | 先建立基线，再按数据迭代降低误报 |
| GPS可信度 | 室内、室外、刚失去定位分别测试 | 明确区分无定位、有效定位和过期位置 |
| 断网降级 | 图传中断、路由器断开 | 避障、照明、SOS本地功能继续运行 |
| 故障隔离 | 分别拔掉一个传感器 | 其余功能继续运行且界面明确提示 |
| 资源稳定性 | 连续运行2 h，记录最小堆和复位原因 | 无看门狗复位、无持续内存下降 |

## 11. 建议在答辩中强调的创新点

不要把创新总结为“用了ESP32、装了很多传感器”。建议表述为：

1. **风险自适应避障**：使用距离趋势和预计碰撞时间，区别于固定阈值蜂鸣；
2. **二阶段异常确认**：把“拐杖异常”与“人员真实求助”分开，针对靠墙误报设计确认窗口；
3. **多模态事件证据链**：一次事件同时包含IMU原因、距离、定位、设备健康和现场图像；
4. **隐私友好图传**：正常状态不主动上传，异常后按需抓拍和远程查看；
5. **单主控可靠调度**：利用ESP32-S3双核和FreeRTOS完成感知、决策、控制、图传与网络协同；
6. **故障降级设计**：单个传感器或网络故障时保留基本安全能力。

## 12. 不建议现在做的事情

- 不为了“分工”或“看起来高级”增加STM32；
- 不在基本功能未稳定前增加摄像头云台；
- 不把心率血氧值简单等同于健康诊断；
- 不承诺当前单超声波和单摄像头能可靠识别所有坑洞、楼梯和盲道；
- 不把Wi-Fi AP描述为互联网远程看护；
- 不使用内部Flash循环保存大量JPEG；
- 不先写复杂神经网络，再补数据集和测试标准。

## 13. 最终建议

项目下一阶段应围绕以下一条主线推进：

> **先用现有硬件完成稳定避障、SOS、GPS和按需图传；再通过FreeRTOS任务化、二阶段异常确认和CareEvent事件证据包形成特色。心率血氧、震动、云台、4G和视觉AI全部作为可选增强，不影响主线验收。**

这个方案的优势是：硬件改动小、与现有代码衔接直接、演示效果清晰、论文中有算法和系统架构可写，也能坦诚处理GPS、Wi-Fi和拐杖IMU的物理限制。

## 14. 官方技术依据

- [Espressif ESP32-S3数据手册：双核处理器及AI/DSP向量指令](https://documentation.espressif.com/esp32-s3_datasheet_en.pdf)
- [ESP-IDF FreeRTOS扩展：`xTaskCreatePinnedToCore`任务绑核接口](https://docs.espressif.com/projects/esp-idf/en/stable/esp32s3/api-reference/system/freertos_additions.html)
- [Espressif官方esp32-camera驱动：OV2640、PSRAM与帧缓冲说明](https://github.com/espressif/esp32-camera)
- [Espressif ESP-DL文档：ESP32-S3轻量推理能力](https://docs.espressif.com/projects/esp-dl/en/release-v1.1/esp32s3/index.html)

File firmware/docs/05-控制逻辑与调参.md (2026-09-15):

# 控制逻辑与调参说明

本阶段在已完成传感器通信调试的基础上，实现了拐杖的本地控制闭环。该逻辑用于课程设计和原型演示；跌倒检测并非医疗或人身安全认证功能。

## 报警优先级

`SOS > FALL > DANGER < 30 cm > WARNING < 50 cm > CAUTION < 100 cm > NORMAL`。

SOS 与跌倒报警会锁存，只有网页、串口或后续物理操作发出的 `CANCEL` 命令才能解除。障碍物报警只依赖最新有效测距值：数据失效后自动退出障碍物状态，避免旧距离持续报警。

蜂鸣器和 LED 均使用非阻塞节奏，不使用 `delay()`：距离越近，提示越密；危险距离、SOS 与跌倒时 LED 闪烁。光照处于自动模式时，照度低于 20 lx 会点亮照明灯；网页或串口可切换为常开、常关或自动。

## SOS 与远程命令

SOS 按键经 30 ms 消抖，确认按下即锁存 SOS。网页 `/api/sos`、`/api/cancel`、`/api/light?mode=on|off|auto` 和串口 `SC1 CMD` 命令不会直接写 GPIO，而是先进入 FreeRTOS 队列，再由主控制循环统一执行。队列繁忙时串口返回 `SC1 ERR command_queue_full`，HTTP 返回 503。

## 跌倒候选规则

`FallDetector` 只消费有效的 JY901S 快照，规则为：

1. 在 2.0 秒窗口内出现低重力（<= 0.55 g）或冲击（>= 2.20 g）；
2. 严格路径要求观察到冲击，随后横滚或俯仰角至少 55 度、合角速度不超过 45 deg/s，并持续 600 ms；
3. 若采到深度低重力（<= 0.40 g），即使 10 Hz 数据漏掉冲击峰值，也可进入旁路；该路径要求相同的倾斜与静止条件持续 1200 ms；
4. 任一路径确认后先进入 `SUSPECTED_FALL`，4 秒未取消再锁存为 `FALL`；取消后 3 秒内不重复触发。

上述原型冻结参数由三轮共 48 次本机记录离线重放得到，全部集中于 `src/config/UserConfig.h`。当前数据上的结果只能说明原型测试通过，不能当作面向真实人群的最终准确率。

## 图传策略

MJPEG 正常状态的帧间隔限制为 150 ms；SOS 或跌倒锁存后取消这一限制，让看护端优先取得现场画面。`/api/status` 增加 `light_mode` 与 `camera_incident`，可据此显示当前模式。

## 上机验收建议

1. 依次遮挡/移开超声波模块，检查 100、50、30 cm 三个分级以及远离障碍后的解除。
2. 遮挡 BH1750，检查自动照明；再用网页或串口切换三种照明模式。
3. 分别按 SOS、使用网页 POST SOS 和串口 `SC1 CMD SOS`，检查本地提示、锁存字段和异常图传；执行 `CANCEL` 后检查恢复。
4. 记录多组 IMU 数据后，按上节规则验证跌倒候选的触发与误报，并仅在调参完成后用于展示。

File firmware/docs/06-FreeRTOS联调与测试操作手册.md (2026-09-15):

# 智能拐杖 FreeRTOS 联调与测试操作手册

## 1. 本次交付范围

本工程以 GOOUUU ESP32-S3-CAM + OV2640 为主控，已将已调通的传感器驱动接入以下闭环：

- Core 1：`SensorTask` 采样 IMU、GPS、超声波、BH1750 和 SOS；`DecisionTask` 执行跌倒检测、避障优先级和状态机；`ActuatorTask` 是蜂鸣器、照明 LED 与 OLED 的唯一写入者。
- Core 0：`NetworkTask` 处理 Wi-Fi AP/STA 重连与状态发布；`TelemetryTask` 处理 `SC1` 串口协议。ESP32 的 HTTP 和相机服务由底层任务继续运行。
- `SensorSnapshotQueue`（长度 1、覆盖旧帧）把最新传感器快照交给决策任务；`ControlCommandQueue`（长度 12）接收按键、网页和串口命令；`ActuatorIntentQueue`（长度 1、覆盖旧指令）交给执行任务。
- 跌倒确认采用双路径：2.0 秒窗口内，严格路径要求冲击后倾角至少 55 度、合角速度不高于 45 deg/s 并保持 600 ms；深度低重力（不高于 0.40 g）可在未采到冲击峰值时改用 1200 ms 保持。确认后先进入 `SUSPECTED_FALL`，4 秒未取消再锁存 `FALL`。
- 避障优先级为 `SOS > FALL > DANGER <30 cm > WARNING <50 cm > CAUTION <100 cm > NORMAL`。超声波阈值带 5 cm 回差，避免边界抖动反复响。
- SOS 和跌倒会提高 MJPEG 图传帧率，并在网页/串口状态中标出 `camera_incident: true`。

> 这是课程设计/原型演示逻辑，不是医疗或人身安全认证功能。跌倒阈值必须按本机实测数据复核后再用于展示。

## 2. 当前硬件边界

已配置的引脚见 `src/config/BoardConfig.h`：I2C 为 GPIO41/42，SOS 为 GPIO40，蜂鸣器为 GPIO1，照明 LED 为 GPIO14，JY901S 为 GPIO39/38，ATGM336H 为 GPIO47/21。相机引脚由板卡固定，不可复用。

需求资料中的震动马达和低电量检测目前没有接入到已给出的板卡引脚，因此本版本不会假装控制它们；本地提醒由蜂鸣器和 LED 实现。若后续增加马达，需先补充 MOS 驱动、供电校核、GPIO 定义，再在 `DigitalOutputs` 中扩展输出，不能直接把马达接到 ESP32 GPIO。

## 3. 首次配置与编译

1. 在 VS Code 中打开 `<local-path>\SmartCane`，等待 PlatformIO 识别 `platformio.ini`。
2. 检查开发板已接到正确 COM 口。当前配置为 `COM8`；若设备管理器显示其他端口，在 `platformio.ini` 中同时修改 `upload_port` 和 `monitor_port`。
3. 按需要编辑 `src/config/UserConfig.h`：
   - 想连接路由器时填写 `WIFI_SSID` 和 `WIFI_PASSWORD`；不要提交真实密码。
   - 留空 SSID 时，设备建立热点 `SmartCane-Camera`，密码 `12345678`。
   - 图像颠倒时设置 `CAMERA_VFLIP` 或 `CAMERA_HMIRROR` 为 `true`。
4. 点击 PlatformIO 左侧栏的 **Build**。首次构建会下载 ESP32-S3 框架、编译器和工具包；必须保持网络可用且不要关闭 VS Code。
5. Build 成功后点击 **Upload**。上传失败时，按住板上的 BOOT，短按 RST，开始写入后松开 BOOT。
6. 打开 **Monitor**，波特率设为 `115200`。不接相机时可以先完成传感器和报警测试，再接 OV2640 测图传，便于定位供电问题。

命令行等效命令（在工程目录执行）：

```powershell
<local-path>\.platformio\penv\Scripts\platformio.exe run -e esp32-s3-cam
<local-path>\.platformio\penv\Scripts\platformio.exe run -e esp32-s3-cam -t upload
<local-path>\.platformio\penv\Scripts\platformio.exe device monitor -p COM8 -b 115200
```

## 4. 启动检查

启动后串口应依次出现：

```text
[SmartCane] boot
[I2C] devices: 0x23/0x5C 0x3C 0x57
[BH1750] online
[Sonar] online at 0x57
[OLED] online
[FreeRTOS] Sensor/Decision/Actuator=Core1, Network/Telemetry=Core0
[SmartCane] ready
```

`0x23` 或 `0x5C` 对应 BH1750，`0x3C` 对应 OLED，`0x57` 对应 I2C 超声波。JY901S 和 GPS 走 UART，因此不会出现在 I2C 扫描中；约 2 秒一次的 `[State]` 行中，`imu=ok` 表示 IMU 在更新，`gps=fix` 仅表示已获得室外定位。

若有某一 I2C 地址缺失，先断电检查该模块 3.3 V、GND、SDA/SCL 和上拉，不要先修改算法阈值。

### GPS 波特率诊断

将 `UserConfig.h` 的 `GPS_BAUD_DIAGNOSTIC_ON_BOOT` 临时设为 `true` 后，每次开机都会在 ESP32 的 115200 串口依次测试 `9600、4800、19200、38400、57600、115200`，每个波特率最多等待 2.5 秒。检测到两条校验正确的 NMEA 语句后会输出：

```text
[GPS-NMEA @9600] $GNRMC,...*xx
[GPS-NMEA @9600] $GNGGA,...*xx
[GPS-DIAG] detected 9600 bps
```

这证明 GPS 的 TX、波特率和 NMEA 数据链路正常；即使尚未定位，也应能看到 NMEA。若所有波特率均失败，日志会显示 `no valid NMEA found`，应检查 GPS TX 到 GPIO47、共地、供电和模块是否正常启动。确认结果后，把 `GPS_BAUD_DIAGNOSTIC_ON_BOOT` 改回 `false`，避免每次开机增加最多 15 秒的诊断等待。

## 5. 网络、网页和上位机

### 5.1 浏览器网页

热点模式下，电脑/手机连接 `SmartCane-Camera` 后访问 `http://192.168.4.1/`；路由器模式下查看 OLED 或串口 `[State]` 行中的 IP，再访问 `http://设备IP/`。

- `GET /api/status`：读取完整 JSON 状态。
- `GET /capture`：抓拍一张 JPEG。
- `GET :81/stream`：MJPEG 视频流。
- `POST /api/sos`：触发 SOS。
- `POST /api/cancel`：解除 SOS/FALL 锁存。
- `GET /api/light?mode=on|off|auto`：切换照明模式。

实体 SOS 键采用“按下切换”逻辑：正常状态下按下即触发并保持 SOS；当 SOS 或 FALL 已锁存时，再按一次即本地解除锁存。按住按键不会重复触发，松开按键没有任何动作。解除 SOS/FALL 不会关闭仍然存在的近障提醒，近障状态会依据下一帧距离数据重新判定。

网页/HTTP 回调不会直接读写 GPIO，只会向控制命令队列投递命令；队列满时 HTTP 返回 503，这是预期的保护行为。

### 5.2 串口命令

串口会周期性输出 `SC1 TEL {JSON}`。可在串口监视器一行一条发送下列命令：

```text
SC1 CMD GET
SC1 CMD SOS
SC1 CMD CANCEL
SC1 CMD LIGHT ON
SC1 CMD LIGHT OFF
SC1 CMD LIGHT AUTO
```

成功会返回 `SC1 ACK ...`；命令队列繁忙时返回 `SC1 ERR command_queue_full`。`NORMAL` 仅代表当前没有报警条件，不代表周边环境安全。

## 6. 分项联调步骤

建议按下表顺序测试，并在每一项记录固件版本、阈值版本、环境、结果和异常。

| 顺序 | 操作 | 预期结果 | 不通过时优先检查 |
|---:|---|---|---|
| 1 | 设备平放，保持障碍物大于 120 cm | OLED/网页为 `NORMAL`，蜂鸣器关闭 | 超声波有效性和距离单位 |
| 2 | 把平整障碍物置于 80 cm、40 cm、20 cm 左右 | 分别为 `CAUTION`、`WARNING`、`DANGER`；蜂鸣节奏逐渐变密 | 超声波正前方、反射面、阈值 |
| 3 | 从危险距离逐渐移远 | 超过阈值加 5 cm 后才降级，超过约 105 cm 才恢复正常 | `OBSTACLE_HYSTERESIS_CM` |
| 4 | 遮住 BH1750 | 自动照明 LED 点亮 | I2C 地址、`DARK_LUX_THRESHOLD` |
| 5 | 网页或串口切换 `LIGHT ON/OFF/AUTO` | ON 常亮，OFF 关闭常规照明，AUTO 按光照；紧急闪烁不被 OFF 抑制 | 命令 ACK 与 GPIO14/MOS |
| 6 | 按 SOS 按键，或发 `SC1 CMD SOS` | `SOS` 锁存、蜂鸣/LED 节奏启动、`camera_incident=true` | GPIO40 高电平、按键消抖、命令队列 |
| 7 | 发 `SC1 CMD CANCEL` 或 POST cancel | SOS/FALL 锁存清除；避障仍可在距离过近时继续提示 | 命令格式与串口波特率 |
| 8 | 连接热点后打开网页和视频流，再重复步骤 2、6 | 传感器与报警继续更新，异常时图传更快 | 5 V 供电余量、Wi-Fi 信号、相机排线 |
| 9 | 室外静止 1–2 分钟 | `gps.valid=true`，网页显示经纬度/卫星数 | 天空视野、GPS 天线与 UART 交叉接线 |

## 7. 跌倒检测的安全调试法

不要直接让人跌倒或用真实人身动作“验证”算法。先从传感器数据和受控的拐杖模型开始：

1. 在串口保存至少 10 组场景：静止、正常摆动、放下拐杖、靠墙、轻碰、快速晃动、受控倾倒、受控冲击后倾倒。
2. 每组记录开始/结束时间和标签。观察 JSON 中 `accel_g`、`roll_deg`、`pitch_deg` 和三个 `gyro_*_dps`。
3. 严格路径应依序出现：候选、冲击、`STRICT_HOLD`（或同时满足两路时的 `BOTH_HOLD`），保持 `FALL_TILT_HOLD_MS` 后进入 `SUSPECTED_FALL`。深度低重力旁路应出现 `DEEP_HOLD`，保持 `FALL_DEEP_TILT_HOLD_MS` 后进入 `SUSPECTED_FALL`；4 秒未取消才会令 `fall_latched=true`。
4. 对每个误报，先判断是冲击阈值、倾角阈值、静止阈值还是保持时间造成，再只改一个参数，重刷后用同一数据集复测。
5. 每次调参都在 `UserConfig.h` 注释记录数据集、日期和结论。正常摆动、靠墙和放下拐杖均不应成为“通过一次演示”的漏测项。

初始参数集中在 `src/config/UserConfig.h`，含义如下：

| 参数 | 原型冻结值 | 调整方向 |
|---|---:|---|
| `FALL_FREE_FALL_G` | 0.55 g | 误触发低重力时降低；漏检低重力时提高 |
| `FALL_DEEP_FREE_FALL_G` | 0.40 g | 深度旁路误报时降低；漏掉无冲击峰值跌倒时谨慎提高 |
| `FALL_IMPACT_G` | 2.20 g | 误触发碰撞时提高；模拟跌倒无冲击时降低 |
| `FALL_TILT_DEG` | 55° | 靠墙/放下误报时提高 |
| `FALL_STILL_GYRO_DPS` | 45 deg/s | 运动中误报时降低 |
| `FALL_SEQUENCE_WINDOW_MS` | 2000 ms | 超时漏检时提高；相隔动作被串联时降低 |
| `FALL_TILT_HOLD_MS` | 600 ms | 严格路径短暂倾斜误报时提高 |
| `FALL_DEEP_TILT_HOLD_MS` | 1200 ms | 深度旁路误报时提高；确认过慢时降低 |

## 8. 长时间稳定性与故障定位

完成分项测试后，保持网页视频流与串口上位机同时开启，连续运行至少 30 分钟；正式展示前建议再运行 2 小时。每 10 分钟记录一次：距离刷新、IMU 在线、最少可用堆、Wi-Fi/IP、是否发生重启。

- 相机开启即重启：优先检查 5 V 电源瞬态电流和 USB 线，不要先降低 FreeRTOS 优先级。
- 图传卡但避障仍正常：降低分辨率/改善 Wi-Fi；传感器和本地报警必须继续工作。
- IMU 长期 `offline`：确认 JY901S TX 接 GPIO39、共地、波特率为 9600。
- GPS 一直无定位：室内无 fix 是正常现象；移到开阔天空测试。
- 网页打不开：确认热点/同一局域网与 OLED IP；AP 模式默认 IP 是 `192.168.4.1`。
- 反复出现队列满：不要提高串口发送频率，先检查上位机是否持续发送控制命令或网络回调是否异常重复。

## 9. 验收记录模板

```text
日期/地点：
硬件版本/电源：
固件提交或文件版本：
UserConfig 参数版本：
Wi-Fi 模式（AP/STA）：
避障（80/40/20 cm）：通过 / 失败，备注：
夜间照明与手动灯：通过 / 失败，备注：
SOS 触发与取消：通过 / 失败，备注：
受控跌倒样本编号与结果：
GPS 室外定位：通过 / 失败，备注：
图传与 30 分钟稳定性：通过 / 失败，备注：
待解决问题：
```

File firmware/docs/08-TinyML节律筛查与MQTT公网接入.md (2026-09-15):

# TinyML 节律筛查与 MQTT 公网接入调试手册

本阶段在原有 MAX30102、跌倒、GPS、相机和局域网网页之上新增两条独立链路：

    MAX30102 → PPG/IBI 特征 → 端侧 TinyML 预筛查 → 网页/串口/MQTT
    ESP32-S3 → 已联网 Wi-Fi/手机热点 → TLS MQTT Broker → 异地电脑或手机

它们不会修改 SOS、疑似跌倒、确认跌倒、避障、照明或相机的控制逻辑。

> 生命体征和节律结果仅用于课程设计演示、趋势观察和“建议复测”的预筛查，不能用于医疗诊断、紧急处置或宣称诊断房颤。

## 1. 已实现的端侧节律筛查

### 1.1 数据处理流程

MAX30102 仍以 100 Hz 采样。现有的去直流、平滑、峰值检测和心率/血氧计算不变；新模块只读取已经计算好的 IBI（相邻心跳间隔）和信号质量，不会直接占用 I2C。

    RED/IR → PPG 预处理 → 峰值 → IBI 历史
                             ├─ 平均 IBI / SDNN / IBI-CV
                             ├─ RMSSD / pNN50 / 最大相邻差
                             └─ 心率 / PPG 信号质量
                                          ↓
                             INT8 六特征 TinyML 基线模型
                                          ↓
                         NORMAL / IRREGULAR / SUSPECTED_AF

模型每 5 秒推理一次，但只有同时满足下列条件时才会输出有效类别：

1. MAX30102 在线，手指持续放在传感器上；
2. PPG 信号质量至少为 0.70；
3. 已稳定采集至少 15 秒，并得到至少 12 个有效 IBI；
4. JY901S 显示拐杖基本静止。移动、抖动或接触松动会显示“请保持静止/信号不足”，不会被误判为异常。

单次较高的 AF-like 结果只显示为“节律不规则”；连续 3 个有效窗口仍为该结果时，才显示“疑似异常节律”并产生 MQTT 事件。它不会自动触发蜂鸣器、SOS、跌倒报警或摄像头事件。

### 1.2 关于 TinyML 的准确表述

当前固件部署的是一个很小的 INT8 六特征分类模型，因此整个“采样 → 特征 → 端侧推理 → 连续确认 → 网页/MQTT”链路可以完整演示，代码没有依赖 TensorFlow Lite Micro 或大型模型。

但当前 RHYTHM_MODEL_CALIBRATED = false，表示附带权重只用于验证系统集成，尚未用同类 MAX30102、同佩戴方式且有 ECG 对照的数据训练和验证。因此答辩时应表述为：

> 基于 PPG 特征的端侧异常节律预筛查基线模型。

不要表述为“已诊断房颤”或“医学级心律失常识别”。后续获得公开标注数据和本机正常 PPG 数据后，只需替换 RhythmClassifier.cpp 中的归一化常量和 INT8 权重，不需要改 MAX30102、FreeRTOS、网页或 MQTT 链路。

### 1.3 网页与串口检查

烧录后，网页会新增“节律筛查”卡片。通常依次看到：

    模块离线 / 请放置手指
    → 采集中
    → 请保持静止（如果拐杖仍在运动）
    → 节律规则

正常使用步骤：

1. 将手指稳定贴在 MAX30102 发光面上，不要大力压住；
2. 让拐杖和手尽量静止；
3. 等待至少 15 到 25 秒；
4. 查看网页卡片和串口 SC1 TEL 中的 vitals.rhythm。

有效 JSON 例子：

~~~json
"rhythm": {
  "state": "NORMAL",
  "model_available": true,
  "model_calibrated": false,
  "valid": true,
  "alert": false,
  "confidence": 0.83,
  "beat_count": 16
}
~~~

MOTION_ARTIFACT、COLLECTING、INCONCLUSIVE 都表示“当前无法可靠判断”，并不代表异常。不要通过刻意制造不规则心跳来测试；没有 ECG 参照时无法安全验证真实异常节律。

可在 UserConfig.h 调整的关键参数：

~~~cpp
RHYTHM_FEATURE_WINDOW_MS
RHYTHM_MIN_IBI_COUNT
RHYTHM_MIN_SIGNAL_QUALITY
RHYTHM_MAX_GYRO_DPS
RHYTHM_ALERT_CONSECUTIVE_WINDOWS
~~~

不要在未保存原始测试结果的情况下随意降低质量门槛或确认次数。

## 2. MQTT 公网远程通信

### 2.1 工作范围

MQTT 解决的是“异地收到状态、GPS、HR、SpO2、FALL/SOS 和节律摘要”，不是把当前 :81/stream MJPEG 视频直接发布到公网：

| 能跨公网实现 | 仍仅限局域网 |
|---|---|
| 设备在线状态、GPS、HR、SpO2、节律筛查 | 当前网页 http://设备IP/ |
| FALL、SOS、疑似跌倒和节律提示事件 | 摄像头 MJPEG :81/stream |
| 经授权的 SOS、解除告警、照明远程命令 | 直接访问 ESP32 的 HTTP 控制接口 |

不要通过端口映射直接暴露 ESP32 网页或摄像头。若后续确实需要公网视频，应单独设计云中转、鉴权和隐私方案。

### 2.2 创建 Broker 后填写配置

请自行在支持 TLS、账号密码和 Topic ACL 的 MQTT 服务中创建一个设备账号，例如 EMQX Cloud。创建账户、接受服务条款和保管密码需要由你本人完成，工程中没有保存真实云端凭据。

编辑 UserConfig.h，按服务商控制台给出的值填写：

~~~cpp
constexpr bool MQTT_ENABLED = true;
constexpr char MQTT_URI[] = "mqtts://你的Broker域名:8883";
constexpr char MQTT_USERNAME[] = "设备账号";
constexpr char MQTT_PASSWORD[] = "设备密码";
constexpr char MQTT_ROOT_CA[] = R"PEM(
-----BEGIN CERTIFICATE-----
粘贴服务商给出的根 CA PEM 全文
-----END CERTIFICATE-----
)PEM";
constexpr char MQTT_TOPIC_ROOT[] = "smartcane";
constexpr char MQTT_DEVICE_ID[] = "device01";

// 先保持 false；确认 ACL 与账号权限正确后才按需要开启。
constexpr bool MQTT_ALLOW_REMOTE_COMMANDS = false;
~~~

要求：

- 正式使用必须采用 mqtts://、端口 8883、根 CA 和账号密码；
- MQTT_ROOT_CA 为空、URI 为空或使用非 TLS URI 时，网页会显示“配置错误”，固件不会偷偷建立不安全连接；
- MQTT_ALLOW_INSECURE_TEST 仅用于隔离的短时实验，公网部署请保持 false；
- Broker ACL 应只允许本账号访问 smartcane/device01/{telemetry,vitals,gps,event,presence,command}；
- 不要把填有真实密码的 UserConfig.h 上传到公开仓库。

设备必须连接能上互联网的路由器或手机热点，即 WIFI_SSID / WIFI_PASSWORD 对应的 STA 网络。回退到 SmartCane-Camera 热点模式后，局域网网页仍能使用，但 MQTT 会自动停止，状态显示为“等待联网”。

TLS 首次联网时固件会先通过 NTP 校时。串口依次可能出现：

~~~text
[MQTT] waiting for NTP time before TLS connection
[MQTT] connecting to mqtts://...
[MQTT] connected
~~~

### 2.3 Topic 与发布频率

以 MQTT_TOPIC_ROOT = smartcane、MQTT_DEVICE_ID = device01 为例：

| Topic | 内容 | 频率/QoS |
|---|---|---|
| smartcane/device01/telemetry | 在线状态、报警、IMU/MAX30102 在线、RSSI | 5 秒，QoS 0 |
| smartcane/device01/vitals | HR、SpO2、信号质量、节律摘要 | 5 秒，QoS 0 |
| smartcane/device01/gps | 实时或最后有效 GPS | 10 秒，QoS 0 |
| smartcane/device01/event | 疑似跌倒、FALL、SOS、连续节律提示 | 立即，QoS 1 |
| smartcane/device01/presence | online / offline | retained，QoS 1 |
| smartcane/device01/command | 远程命令 | 订阅 QoS 1，默认关闭 |

公网不上传原始 RED/IR PPG，也不上传视频。这样可降低隐私、流量和 Broker 负担。

### 2.4 跨网络测试

1. 让 ESP32 连接手机热点 A 或路由器 A，确认该网络能访问互联网；
2. 在另一台电脑/手机连接网络 B；
3. 使用 MQTTX 等客户端，以相同 Broker、TLS CA、账号密码连接；
4. 订阅主题：

~~~text
smartcane/device01/#
~~~

5. 观察 presence 为 online，并每 5 至 10 秒收到三类周期消息；
6. 在本地触发 SOS、疑似跌倒和确认 FALL，确认 event 立即到达；
7. 断开设备热点或路由器，再恢复网络，确认 MQTT 自动恢复并继续上报。

开启远程命令前，先确认 ACL 已限制到设备自己的 command Topic。可发送的纯文本命令只有：

~~~text
sos
cancel
light:on
light:off
light:auto
~~~

命令仍会先进入原有 FreeRTOS 命令队列；MQTT 回调不会直接驱动蜂鸣器、灯或报警状态机。

## 3. 常见状态

| 网页 MQTT 状态 | 含义与处理 |
|---|---|
| 未启用 | MQTT_ENABLED = false，这是默认状态 |
| 配置错误 | URI、设备 ID、Topic 根或 TLS CA 缺失；检查配置 |
| 等待联网 | 当前是 AP 模式或 STA 尚未连上可上网 Wi-Fi |
| TLS 校时中 | 刚联网，等待 NTP 获得正确时间 |
| 连接中 | 正在 DNS/TLS/MQTT 建连，检查 Broker 地址、端口和账号 |
| 已连接 | 公网遥测已工作 |
| 连接错误 | 检查 CA 是否完整、账号密码、ACL、网络是否拦截 8883 |

## 4. 代码位置

- src/control/VitalsProcessor.*：IBI/HRV 特征提取；
- src/control/RhythmClassifier.*：INT8 特征模型、静止门槛和连续确认；
- src/services/MqttRemoteService.*：TLS MQTT、自动重连、Topic、事件和命令白名单；
- src/app/SmartCaneApp.*：将两者接入已有的 Core 1 SensorTask 与 Core 0 NetworkTask；
- src/services/WifiCameraServer.cpp：本地网页的节律和 MQTT 状态卡片。

编译不会上传固件；完成配置后，先 Build，再 Upload，最后以串口和 MQTT 客户端进行跨网络验证。

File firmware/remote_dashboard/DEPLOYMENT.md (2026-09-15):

# 公网 IP 部署、调试与验收指南

本指南以本课程项目已经实际走通的方案为主：

```text
ECS 公网 IPv4 + Nginx/HTTP + Docker remote_dashboard
```

域名、DNS、Certbot 和 HTTPS 不再是本轮演示的前置条件，而是长期处理真实 GPS 与健康数据前的安全升级项。当前公网网页保持只读。

## 0. 2026-09-02 当前部署状态

已经完成：

- 阿里云 ECS 已运行 Docker Compose；
- `dashboard` 容器为 `healthy`；
- `127.0.0.1:8080/livez` 与 `/readyz` 在 Demo 模式返回 HTTP 200；
- Nginx 监听公网 80，并反向代理到 `127.0.0.1:8080`；
- ECS 实例已经加入放行 TCP 80 的安全组；
- 通过公网 IP 可以打开网页登录验证。

当前尚未完成：

- 当前为 `SMARTCANE_DEMO=true`，页面是服务器模拟数据；
- 实机不在现场，尚未验证 ESP32 → EMQX → ECS → 异地浏览器的最终完整链；
- 尚未留下手机关闭 Wi-Fi 后的 4G/5G 验收截图；
- 未购买域名，当前没有 HTTPS。

详细证据边界见 [公网IP部署验收记录.md](公网IP部署验收记录.md)。

## 1. 理解两种运行模式

### Demo 模式

```text
公网浏览器 → ECS/Nginx → remote_dashboard → DemoFeed 模拟数据
```

`.env` 设置：

```dotenv
SMARTCANE_DEMO=true
```

它不连接真实智能拐杖，也不要求实机在身边，适合部署和页面演示。

### 真实模式

```text
ESP32 → 可上网 Wi-Fi → EMQX Cloud → ECS remote_dashboard → 异地浏览器
```

`.env` 设置：

```dotenv
SMARTCANE_DEMO=false
```

ESP32 只连接 EMQX 分配的 Broker 主机名，不连接 ECS 的 80 端口，也不需要知道网页公网 IP。网页以后从公网 IP 换成域名时，不需要修改 ESP32 MQTT 固件。

## 2. 部署前准备

需要具备：

1. 一台有公网 IPv4 和公网带宽的 Linux ECS（Ubuntu 22.04/24.04）；
2. 当前 ECS 实例已加入正确的安全组；
3. 安全组入方向允许 TCP 80，不能把 8080 暴露到公网；
4. 服务器允许出站 TCP 8883（MQTT TLS）和 443（高德地图与软件更新）；
5. 真实模式需要 EMQX 独立网页只读账号；
6. 显示静态地图需要高德“Web 服务”Key。

当前网页登录使用 HTTP Basic Auth。它在普通 HTTP 下不能加密用户名和密码，因此公网 IP + HTTP 仅用于短期课程演示。必须使用独立临时密码，不能复用阿里云、邮箱、MQTT 或其他重要账号密码。

## 3. 创建 EMQX 网页只读账号

在 EMQX 控制台新建一个只给 Python 后端使用的账号，不要复用 ESP32 发布账号。

该账号只允许订阅：

```text
smartcane/device01/presence
smartcane/device01/telemetry
smartcane/device01/vitals
smartcane/device01/gps
smartcane/device01/event
```

ACL 要求：

- 允许 `subscribe` 上述五个精确 Topic；
- 禁止任何 `publish`；
- 禁止订阅 `smartcane/device01/command`；
- 不授予 `smartcane/#` 或 `#` 通配权限。

规则显示顺序不会改变匹配结果；需要关注的是权限动作、Topic 和是否存在更宽泛或冲突的规则。

## 4. Windows 本机 Demo（可选）

在 VS Code PowerShell 进入 `remote_dashboard`：

```powershell
Copy-Item .env.example .env
powershell -ExecutionPolicy Bypass -File .\run.ps1 -Install
powershell -ExecutionPolicy Bypass -File .\run.ps1 -Demo
```

浏览器打开 `http://127.0.0.1:8080`。这里是本机回环地址，不是公网地址。

## 5. ECS 配置 `.env`

在阿里云 Workbench 终端执行：

```bash
cd /opt/smartcane/remote_dashboard
cp .env.example .env
chmod 600 .env
nano .env
```

首次无实机演示使用：

```dotenv
MQTT_HOST=EMQX分配的公网主机名
MQTT_PORT=8883
MQTT_USERNAME=网页只读账号
MQTT_PASSWORD=网页只读账号密码
MQTT_DEVICE_ID=device01
MQTT_TOPIC_ROOT=smartcane
MQTT_CLIENT_ID=smartcane-web-device01
MQTT_CA_FILE=

AMAP_STATIC_MAP_KEY=高德Web服务Key

DASHBOARD_USERNAME=guardian
DASHBOARD_PASSWORD=独立临时强密码
DASHBOARD_AUTH_REQUIRED=true
SMARTCANE_DEMO=true
```

注意：

- `MQTT_HOST` 是 EMQX Cloud 分配的主机名，不是 ECS 公网 IP；
- `.env` 不上传到 Git，不放进截图；
- 修改 `.env` 后要重新创建容器才能可靠生效。

## 6. Docker Compose 启动与检查

```bash
cd /opt/smartcane/remote_dashboard
sudo docker compose up -d --build
sudo docker compose ps
```

检查后端：

```bash
curl -i http://127.0.0.1:8080/livez
curl -i http://127.0.0.1:8080/readyz
```

Demo 模式两个接口都应返回 HTTP 200 与：

```json
{"ok":true}
```

真实模式中：

- `/livez` 为 200：网页进程存活；
- `/readyz` 为 200：Python 后端已连接 EMQX；
- `/readyz` 为 503：MQTT 尚未连接，但不等于网页程序崩溃；
- `/readyz` 为 200 也不等于智能拐杖在线，设备在线还需要新鲜 telemetry。

查看日志：

```bash
sudo docker compose logs --tail=100 dashboard
```

## 7. 无域名 Nginx 公网入口

安装 Nginx：

```bash
sudo apt update
sudo apt install -y nginx
sudo systemctl enable --now nginx
```

复制本项目的公网 IP 模板：

```bash
cd /opt/smartcane/remote_dashboard
sudo cp deploy/nginx-smartcane.conf /etc/nginx/sites-available/smartcane
```

模板使用：

```nginx
listen 80 default_server;
listen [::]:80 default_server;
server_name _;
```

因此不需要把公网 IP 写死到源代码。禁用 Ubuntu 默认站点并启用本项目：

```bash
sudo unlink /etc/nginx/sites-enabled/default
sudo ln -sfn /etc/nginx/sites-available/smartcane /etc/nginx/sites-enabled/smartcane
sudo nginx -t
sudo systemctl reload nginx
```

`unlink` 提示文件不存在时可忽略。`nginx -t` 必须显示：

```text
syntax is ok
test is successful
```

不要把 Markdown 的三个反引号、`nginx`、`perl` 等代码块标记复制进配置文件。

检查代理：

```bash
curl -i http://127.0.0.1/livez
curl -i http://127.0.0.1/readyz
```

## 8. ECS 安全组

必须从“当前 ECS 实例详情 → 安全组”进入，确认安全组确实关联到该实例。仅仅创建安全组而未将实例加入，不会放通公网访问。

HTTP 演示规则：

| 项目 | 内容 |
|---|---|
| 方向 | 入方向 |
| 策略 | 允许 |
| 优先级 | 1 |
| IP 版本 | IPv4 |
| 协议 | TCP |
| 目的端口 | 80/80 |
| 来源 | `0.0.0.0/0`（需要异地任意网络访问时） |

保持以下边界：

- ECS 入方向不开放 8080；
- ECS 入方向不开放 8883，后端是主动出站连接 EMQX；
- SSH 22 尽量只允许管理者来源地址；
- HTTPS 尚未启用时，443 规则不会产生网页服务。

服务器检查：

```bash
sudo ss -lntp | grep -E ':80 |:8080 '
sudo ufw status verbose
```

正常应看到 Nginx 监听 `0.0.0.0:80`，Docker 仅监听 `127.0.0.1:8080`。ECS 从内部访问自己的公网 IP 可能因云网络回环而超时，应从外部电脑或手机验证。

## 9. 公网 IP 与手机验收

在 ECS 控制台实例详情复制“公网 IP”或已绑定的 EIP。不要使用 `10.*`、`172.16-31.*`、`192.168.*` 私网地址。

电脑浏览器明确输入：

```text
http://ECS_PUBLIC_IP
```

不要输入 `https://`。输入 `.env` 中的网页账号与密码。

手机验收：

1. 关闭手机 Wi-Fi，只保留 4G/5G；
2. 打开相同的 `http://ECS_PUBLIC_IP`；
3. 登录并确认页面能持续更新；
4. 保存一张能体现移动网络与页面内容的截图。

接口测试：

```powershell
curl.exe --max-time 15 -i http://ECS_PUBLIC_IP/livez
```

`/livez`、`/readyz` 是无需登录的运行探针。主页与 `/api/*` 数据接口需要登录。

## 10. 实机恢复后切换真实模式

```bash
cd /opt/smartcane/remote_dashboard
nano .env
```

修改：

```dotenv
SMARTCANE_DEMO=false
```

重新创建容器：

```bash
sudo docker compose up -d --force-recreate
sudo docker compose logs --tail=100 -f dashboard
```

看到后端 MQTT connected 后按 `Ctrl+C` 只会退出日志，不会停止容器。

实机最小验收：

1. ESP32 连接能够上网的路由器或手机热点；
2. 串口确认 MQTT connected；
3. 手机关闭 Wi-Fi，从公网 IP 登录；
4. 确认设备在线、HR/SpO₂/PPG/节律和 GPS 随实机数据变化；
5. GPS 失星后应显示最后有效位置；
6. 触发 SOS，确认本地声光和网页事件；再按实体按钮解除；
7. 按受控流程触发疑似跌倒与跌倒；
8. 断开 ESP32 网络，确认约 15 秒后网页显示离线，再验证恢复；
9. 保存串口、网页和 MQTT 日志。

公网网页没有远程控制；摄像头继续通过智能拐杖近场页面查看。

## 11. 可选升级：域名与 HTTPS

课程临时演示可以停留在公网 IP + HTTP。长期查看真实 GPS、健康数据时，建议完成：

1. 购买并实名认证域名；
2. 若服务器位于中国内地，先按阿里云要求确认并办理备案；
3. 添加 A 记录指向 ECS 公网 IP；
4. 将 Nginx 中两行 `default_server` 删除，并把 `server_name _;` 改为真实域名；
5. 安全组开放 TCP 443；
6. 安装 Certbot 并申请证书。

```bash
sudo apt install -y certbot python3-certbot-nginx
sudo certbot --nginx --redirect -d cane.example.com
sudo certbot renew --dry-run
```

域名方案完成后，最终只使用 `https://cane.example.com`。不要在证书验证前启用长期 HSTS。

## 12. 常见问题

### 公网超时

若 `127.0.0.1/livez` 为 200，而外部访问超时：

- 确认实例已加入所修改的安全组；
- 运行阿里云“安全组规则诊断”，检查 TCP 80；
- 确认公网 IP 与公网带宽有效；
- 检查网络 ACL；
- 关闭本地 VPN/代理后重试。

### HTTP 502

表示 Nginx 已收到请求，但无法连接后端：

```bash
sudo docker compose ps -a
curl -i http://127.0.0.1:8080/livez
sudo tail -n 50 /var/log/nginx/error.log
```

### HTTP 404

通常是请求落入 Ubuntu 默认站点。确认默认站点已禁用、本项目软链接已启用，并重新执行 `nginx -t` 与 reload。

### 页面显示设备离线

- 确认不是误把 Demo/真实模式理解反了；
- 检查后端 MQTT 日志；
- 检查五个精确 Topic ACL；
- 检查 ESP32 和后端 `MQTT_DEVICE_ID` 都为 `device01`；
- telemetry 超过 15 秒没有更新会自动显示离线。

### 高德地图不显示

- `.env` 必须填写高德“Web 服务”Key；
- 服务器必须能访问 `https://restapi.amap.com`；
- GPS 必须先提供有效坐标；
- 即使静态图失败，经纬度与详细位置链接仍可使用。

### 容器重启后事件列表清空

当前事件仅保存在内存中。课程阶段可以接受；需要长期追溯时再增加数据库。

## 13. 本阶段明确不做

- 不开放公网 SOS、取消告警和灯光控制；
- 不让浏览器直接连接 MQTT；
- 不把 MQTT 凭据写进前端 JavaScript；
- 不把 ESP32 MJPEG `:81/stream` 暴露到公网；
- 不通过 MQTT 传视频；
- 不把当前 HTTP 方案描述为可长期承载隐私数据的安全生产部署。

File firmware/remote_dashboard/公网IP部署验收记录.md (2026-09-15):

# SmartCane 公网 IP 部署验收记录

记录日期：2026-09-02

## 当前结论

远程监护网页已经部署到阿里云 ECS，并可通过“公网 IPv4 + Nginx + HTTP”进入网页登录页。域名、DNS 与 Certbot 不再作为本轮课程演示的阻塞项。

本次验证的是云端网页基础设施和 Demo 数据链，不应写成“真实智能拐杖已经完成端到端公网验收”。实机当前不在现场，完整真实链路仍需在设备恢复后补一次短程回归。

## 已核对证据

| 检查项 | 结果 | 证据/说明 |
|---|---|---|
| Docker Compose | 通过 | `dashboard` 容器为 `healthy` |
| 后端存活 | 通过 | `127.0.0.1:8080/livez` 返回 HTTP 200 与 `{"ok":true}` |
| Demo 就绪 | 通过 | `127.0.0.1:8080/readyz` 返回 HTTP 200 |
| Nginx 反向代理 | 通过 | `127.0.0.1/livez` 返回 HTTP 200 |
| 端口边界 | 通过 | Nginx 监听 `0.0.0.0:80`；Docker 仅绑定 `127.0.0.1:8080` |
| Ubuntu UFW | 通过 | 状态为 inactive，未拦截 80 |
| ECS 安全组 | 通过 | 当前实例已关联允许 TCP 80 的安全组；关联后公网访问恢复 |
| 公网登录页 | 通过 | 公网 IP 页面可打开并显示登录验证 |
| 域名/HTTPS | 有意延期 | 当前未购买域名，使用 HTTP 公网 IP；只适合短期演示 |
| 实机真实数据 | 待验证 | 当前 `SMARTCANE_DEMO=true`，数据由服务器模拟 |
| 手机 4G/5G | 待留证 | 应关闭 Wi-Fi 后保存一次公网访问截图 |

## 本轮源码验证

- 远程后端自动测试：20 项全部通过（含 Docker 回环端口与 Nginx/SSE 部署边界测试）。
- 前端 `app.js`：Node.js 语法检查通过。
- ESP32 主工程：PlatformIO `esp32-s3-cam` release 编译通过；RAM 使用 55,308 B（16.9%），Flash 使用 1,012,877 B（51.5%）。

公网 IP 与域名都没有被硬编码到前端或 ESP32 固件中。浏览器继续使用同源相对接口，ESP32 继续连接 EMQX Broker，因此以后更换 ECS IP 或升级域名时不需要重写业务代码。

## 当前访问链

```text
电脑/手机浏览器
    ↓ HTTP（公网 IP）
阿里云 ECS Nginx :80
    ↓
127.0.0.1:8080 remote_dashboard
    ↓
DemoFeed（当前模拟数据）
```

实机恢复后的目标链路：

```text
ESP32（可上网的 Wi-Fi/热点）
    ↓ MQTT TLS/8883
EMQX Cloud
    ↓ MQTT TLS/8883
ECS remote_dashboard
    ↓ Nginx + 公网 IP
异地亲属浏览器
```

ESP32 不连接 ECS 的 80 端口，也不需要知道网页公网 IP；它仍然连接 EMQX 分配的 Broker 主机名。网页使用公网 IP 或以后改用域名，都不需要改 ESP32 MQTT 固件。

## 实机回来后的最小验收

1. 在服务器 `.env` 中设置 `SMARTCANE_DEMO=false`，保留真实 MQTT 只读账号。
2. 执行 `sudo docker compose up -d --force-recreate`。
3. 确认 `/livez` 为 200；`/readyz` 为 200 只表示后端已连接 Broker。
4. ESP32 接入可上网的 Wi-Fi，串口确认 MQTT connected。
5. 手机关闭 Wi-Fi，通过公网 IP 登录，确认设备在线且数据随实机变化。
6. 验证 GPS、生命体征、SOS、疑似跌倒/跌倒事件与设备离线/恢复。
7. 保存网页、串口与 MQTT 日志作为最终端到端证据。

## 安全边界

- 当前 HTTP Basic 登录在 HTTP 下不加密；必须使用独立临时密码，不得复用阿里云、邮箱或 MQTT 密码。
- 公网只开放 80；8080 不开放，MQTT 8883 是服务器主动出站连接，也不开放为 ECS 入站端口。
- 公网网页保持只读，不提供 SOS、取消告警和灯光远程控制。
- 摄像头继续使用近场页面，不向公网暴露 ESP32 的 81 端口。
- 若长期展示真实 GPS/生命体征，应升级为域名 + HTTPS，或使用仅授权家庭成员加入的加密专网。

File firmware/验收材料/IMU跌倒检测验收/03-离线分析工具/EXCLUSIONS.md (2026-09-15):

# 离线分析排除项

离线重放有效集排除以下文件：

- `imu_20260831_185152_141_T014_fall_backward.csv`

排除原因：该记录在后向倾倒动作完成前停止，总时长2.59秒，动作真正开始后仅保留约200毫秒动态数据，最终倾角45.43°，没有记录落地后的倾斜静止保持段，无法判定算法是否应当触发。

原始文件没有删除，保存在：

`../01-采集数据/第4轮-冻结参数独立验收/imu_20260831_185152_141_T014_fall_backward.csv`

随后完成的后向倾倒重测文件为：

`imu_20260831_185218_860_T015_fall_backward.csv`

该重测记录完整，并由深度失重路径进入 `SUSPECTED_FALL`。

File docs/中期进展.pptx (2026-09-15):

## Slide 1

基于ESP32的智能拐杖系统

嵌入式系统高级实验中期报告

小组成员：成员A、成员B、成员C
2026 / 8 / 13

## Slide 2

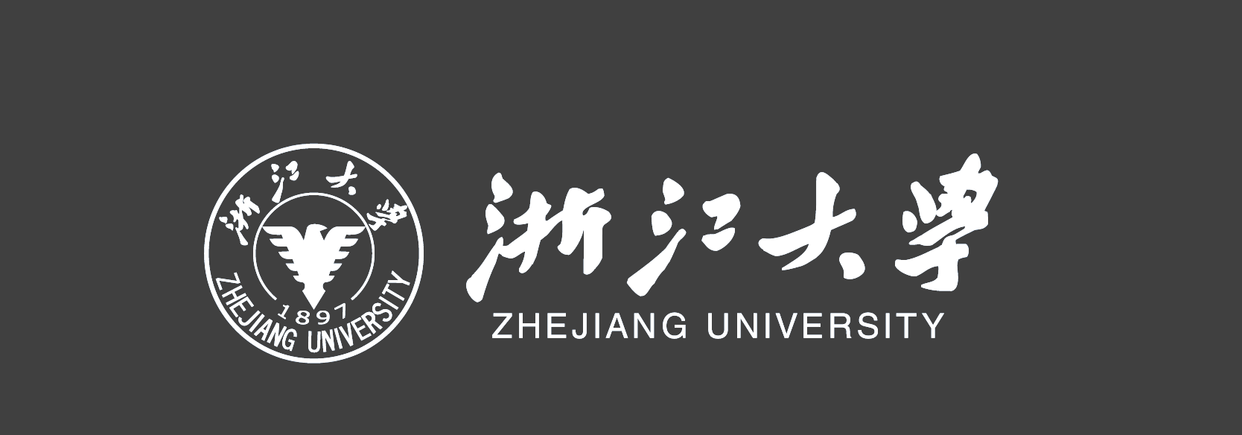
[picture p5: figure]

目 录

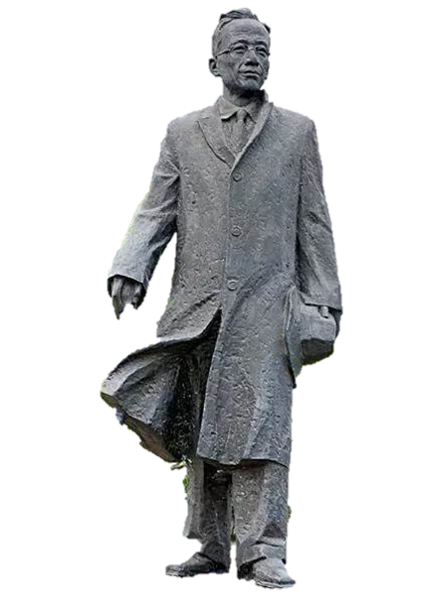
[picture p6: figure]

1

总述

2

系统架构

3

硬件方案

4

软件方案

当前成果

5

下一阶段规划

6

CONTENTS

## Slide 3

01

总述

截至中期，SmartCane 已在 ESP 32-S 3-CAM 单主控上完成从传感器驱动到远程监控的全链路集成，已完成的主要工作包括：
- 传感器层：HC-SR 04 超声波非阻塞测距与三级避障、BH 1750 照度检测与自动照明、JY 901 S 姿态采集与组合规则式跌倒检测、ATGM 336 H GPS 定位与最后有效位置保存。
- 调度层：双核 FreeRTOS 将传感器/决策/执行放在 Core 1，网络/遥测放在 Core 0，任务间通过队列传递数据而非互相操作硬件。
- 控制层：分级告警状态机实现 SOS/FALL 锁存与近障分级，蜂鸣器和 LED 以非阻塞节奏输出。
- 网络层：OV 2640 摄像头提供 MJPEG 图传与单帧抓拍，Wi-Fi 在路由器和热点模式间自动切换。
- 上位机：SC 1 串口协议以 5 Hz JSON 遥测发布状态，Windows 上位机同时承载串口监控、Wi-Fi 图传和 GPS 矢量地图三条数据链路。

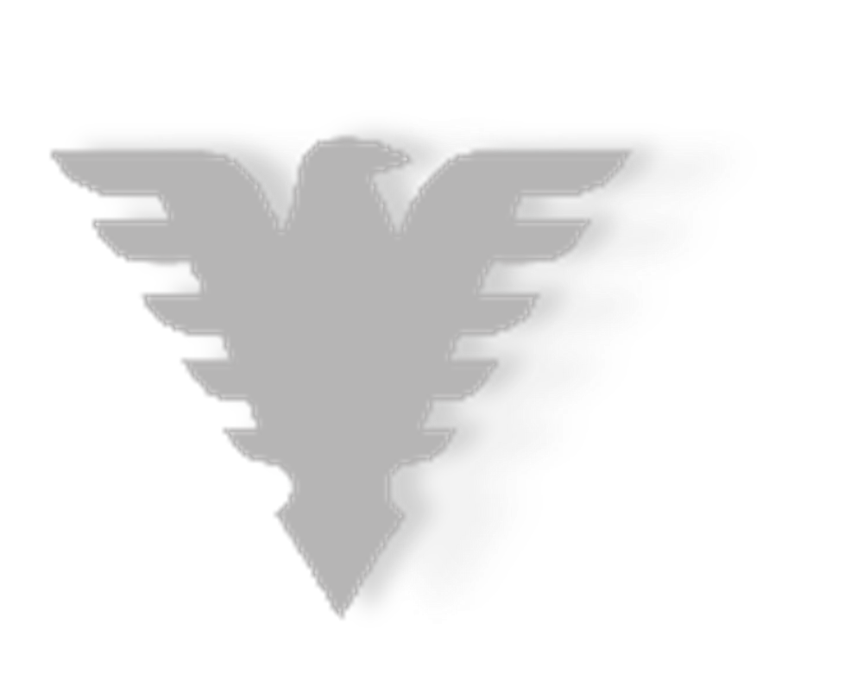
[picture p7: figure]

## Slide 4

02

系统架构

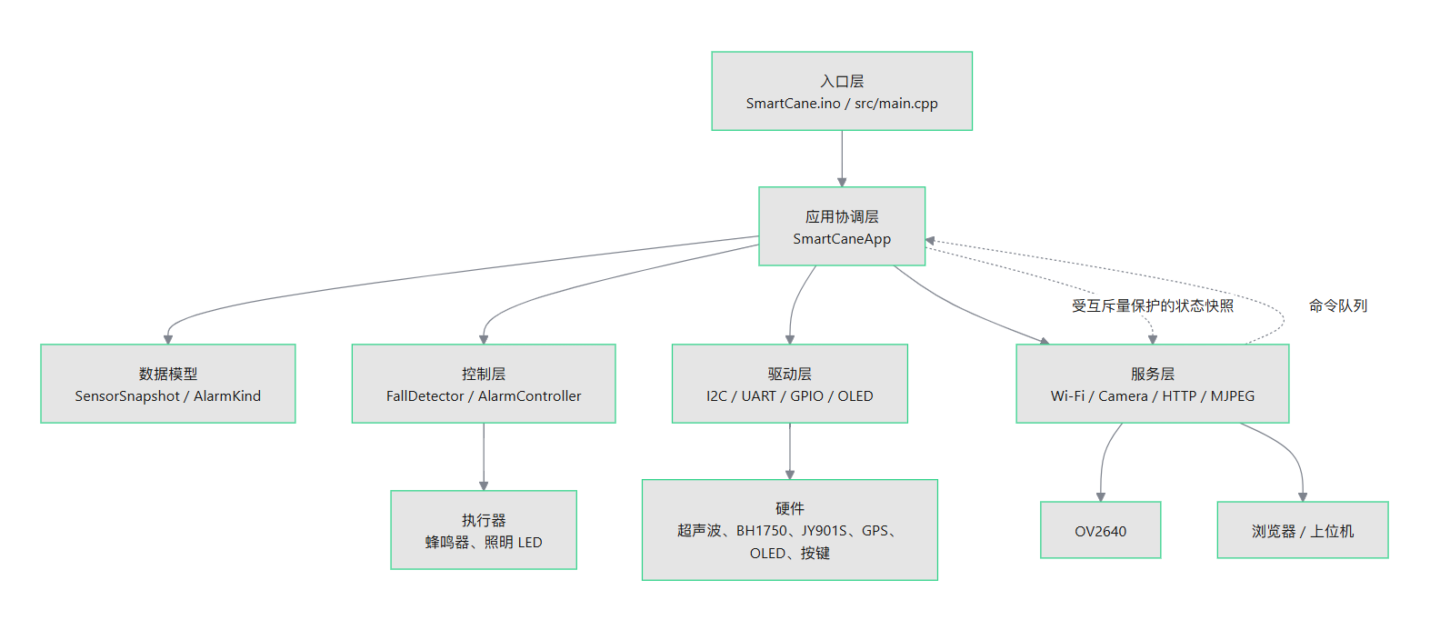
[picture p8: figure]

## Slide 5

02

系统架构

各分层职责

层级 | 职责
入口层 | 提供 setup() 和 loop()
应用层 | 初始化、周期调度、模块协作、状态发布
配置层 | 引脚、波特率、Wi-Fi、阈值和周期参数
控制层 | 跌倒检测和分级告警状态机
驱动层 | 设备协议、采样、校验、GPIO 输出
模型层 | 模块间共享的数据结构和枚举
服务层 | Wi-Fi、摄像头、HTTP、网页和 API

双入口设计

- Arduino IDE 使用根目录 SmartCane.ino
- PlatformIO 使用 src/main.cpp
- 通过 SMARTCANE_PLATFORMIO 宏和 build_src_filter 互斥，一次构建只启用一个入口
- 两个入口最终都只做：setup() 调用 app.begin()，loop() 调用 app.update()

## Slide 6

03

硬件方案-主控与构建配置✅

- 主控：GOOUUU ESP 32-S 3-CAM 开发板，双核 ESP 32-S 3 处理器
- Flash：8 MB
- PSRAM：OPI PSRAM
- 分区表：min_spiffs
- 调试串口：115200 波特率
- 相机引脚由板卡原理图固定占用 GPIO 4～18 中的多个引脚，不可再分配给外围模块
- BoardConfig.h 中的静态断言会阻止外围 I 2 C SDA 与相机 SCCB SDA 被配置成同一引脚
- 因 Windows 版 ESP 32 链接器对中文路径兼容性不稳定，platformio.ini 已把构建目录放到系统临时目录

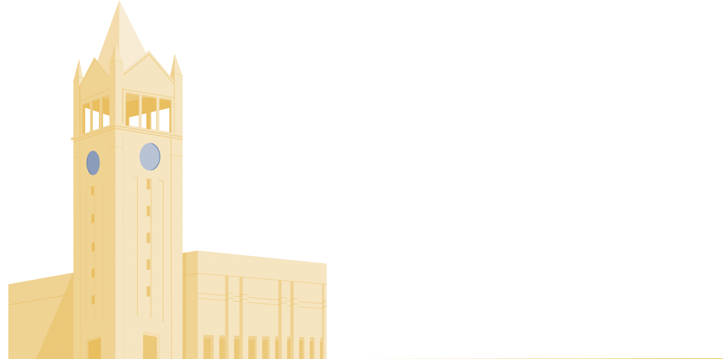
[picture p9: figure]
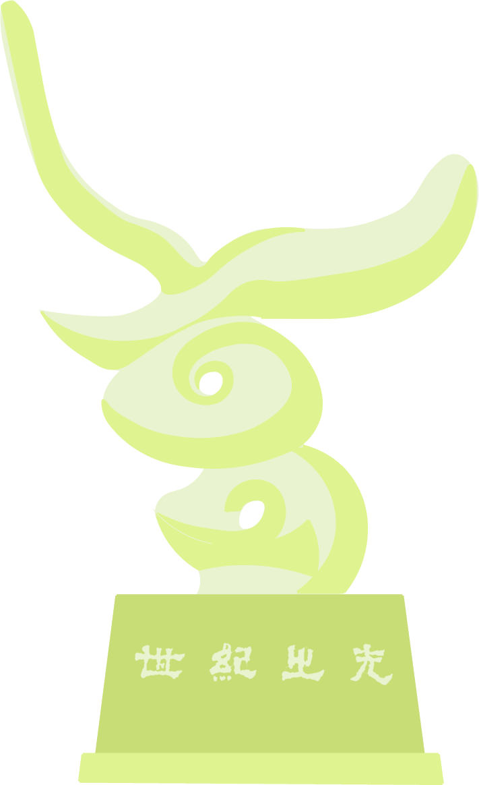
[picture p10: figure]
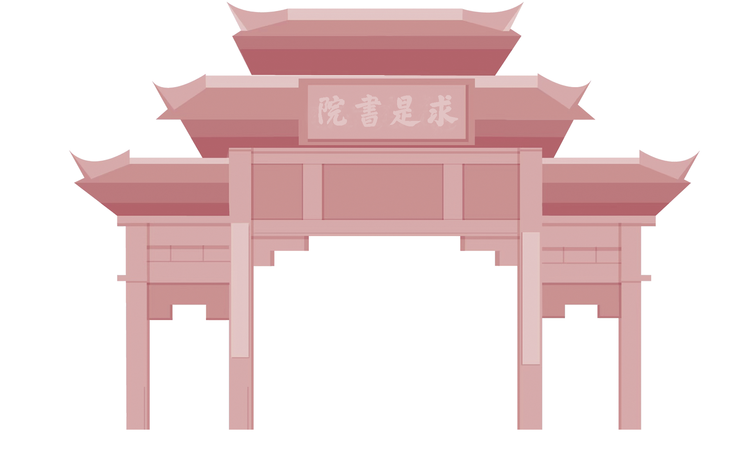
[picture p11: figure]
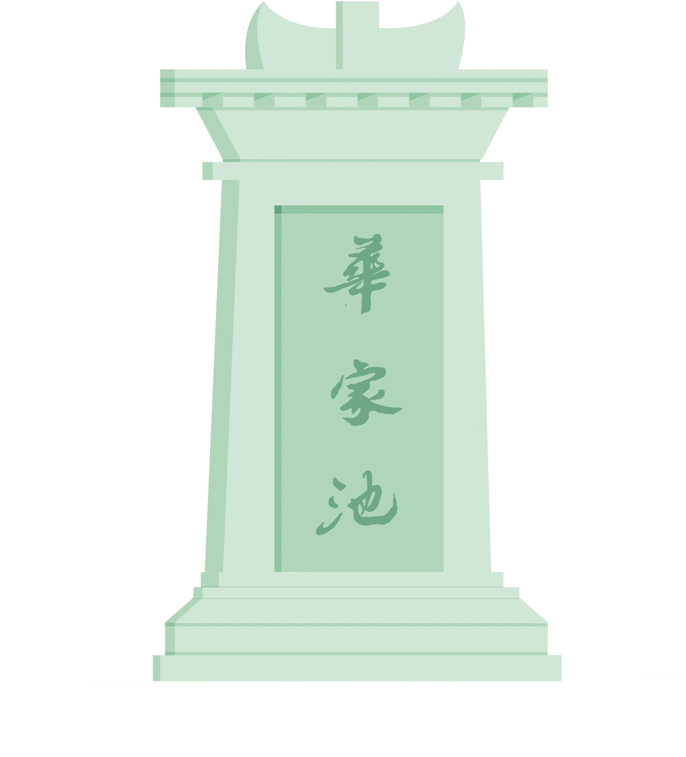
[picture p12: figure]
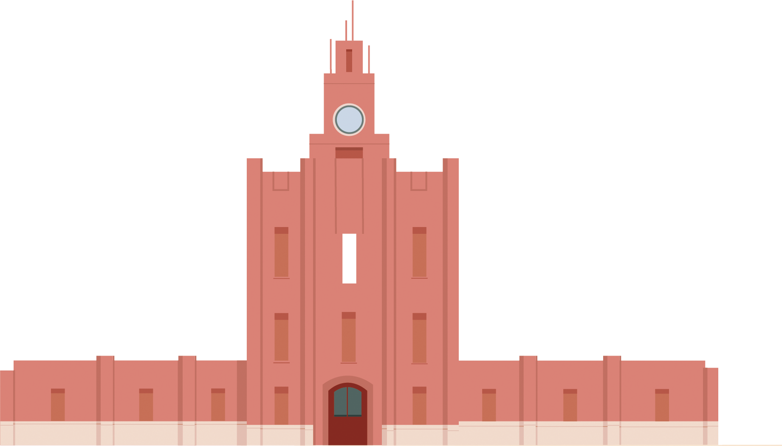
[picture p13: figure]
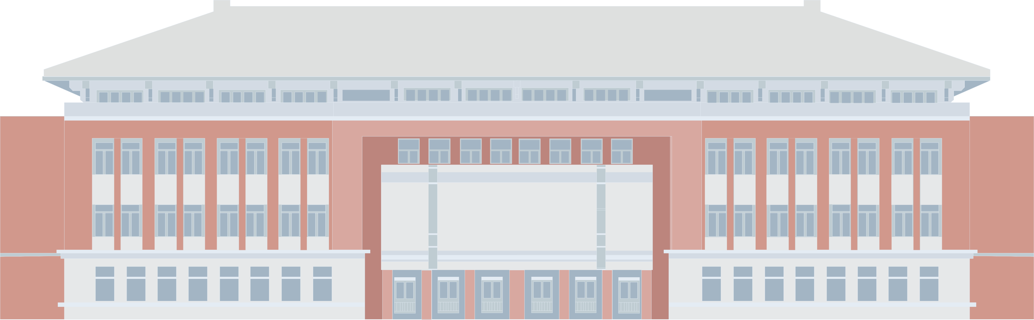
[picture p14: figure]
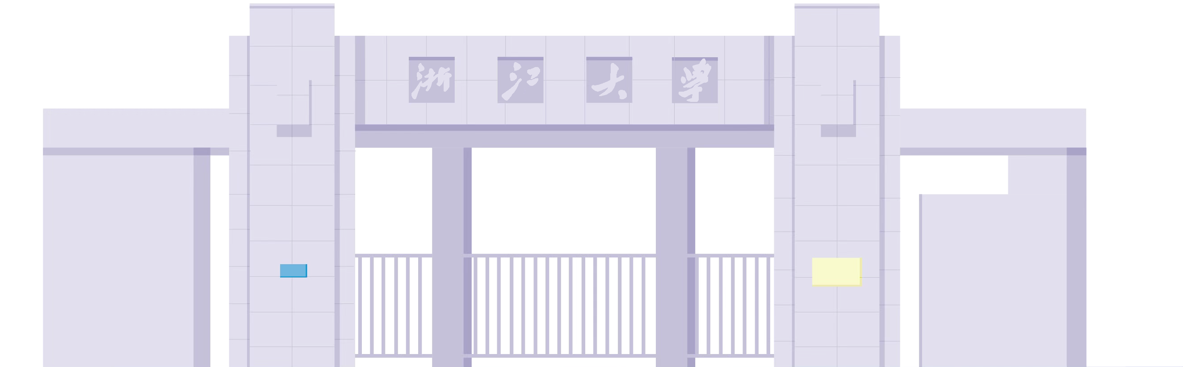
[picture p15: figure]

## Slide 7

03

硬件方案-传感器与执行器✅

驱动 | 实现要点
HC-SR04 (I2C) | 写 0x01 → 等 130 ms → 读 24 位微米值；非阻塞触发
JY901S (IMU) | 解析 0x55 帧，输出加速度/角速度/欧拉角
ATGM336H (GPS) | 校验 NMEA RMC/GGA，保留最后有效位置
BH1750 | 自动识别 0x23/0x5C 双地址，高分辨率模式
SSD1306 | 自带轻量显示驱动和英数字体
SOS 按键 | 30 ms 消抖，边沿触发，长按不重复入队
蜂鸣器 / LED | MOS 驱动，非阻塞节奏控制

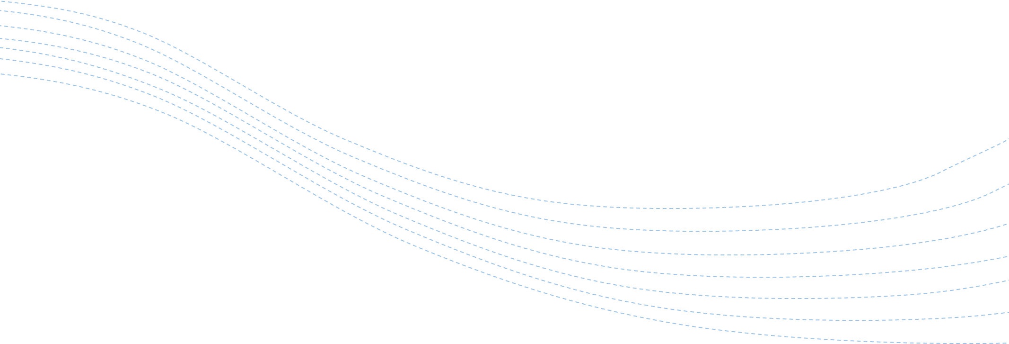
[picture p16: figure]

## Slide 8

04

软件方案-双核调度✅

工程已完成双核 FreeRTOS 任务划分： 关键规则：
- Core 1 负责传感器/决策/执行
- Core 0 负责网络/遥测，任务间通过队列传递数据。

任务 | 核心 | 职责
SensorTask | Core 1 | 采样全部传感器，生成原始快照
DecisionTask | Core 1 | 跌倒检测与状态机决策
ActuatorTask | Core 1 | 蜂鸣器、LED、OLED 的唯一写入者
NetworkTask | Core 0 | Wi-Fi 重连与状态发布
TelemetryTask | Core 0 | SC 1 串口遥测
摄像头/HTTP | 默认 | MJPEG 流与网页请求

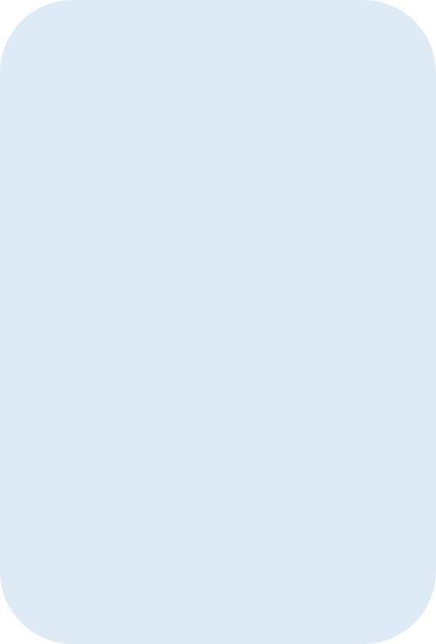
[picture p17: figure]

1. 只有 SensorTask 读传感器，只有 ActuatorTask 写执行器
2. DecisionTask 只读快照、只输出命令
3. HTTP 回调只入队，不直接改状态机
4. 队列满时返回 503 / SC1 ERR

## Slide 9

04

软件方案-Wi-Fi 图传与网络服务✅

传感器驱动
独立驱动，封装协议解析，不决定告警等级。带 valid 标志和超时失效。全部非阻塞，不用 delay()。

Wi-Fi

1

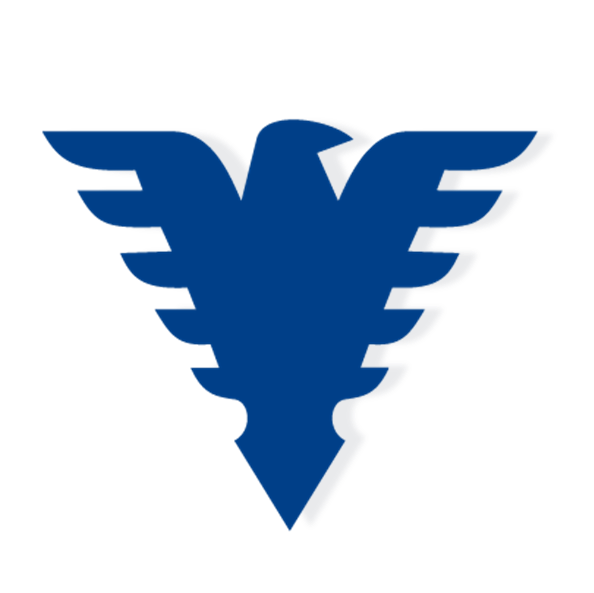
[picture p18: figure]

2

连路由器失败/断线 12 秒 → 回退热点 SmartCane-Camera

3

摄像头

有 PSRAM 用 VGA，无则降级 QVGA；MJPEG 走 81 端口

4

网页

- /api/status（状态 JSON）
- /capture（抓拍）
- :81/stream（MJPEG）
- /api/sos、/api/cancel、/api/light

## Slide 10

04

软件方案-具体实现✅

Windows 上位机 SC1 通信协议

- 串口全量遥测与控制
- Wi-Fi MJPEG 图传显示
- GPS 在线/离线矢量地图（OpenStreetMap）
- GeoJSON / GPX / KML 轨迹导入
- 只展示原始快照，不在电脑端自行实现业务判断

- CH340 UART0，115200，5 Hz JSON 遥测
- 图像走 Wi-Fi，与串口互不影响
- 遥测覆盖：系统状态、距离/照度、IMU、GPS、网络/相机
- 命令：PING、GET、SOS、CANCEL、LIGHT

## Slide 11

05

当前成果-实物展示✅

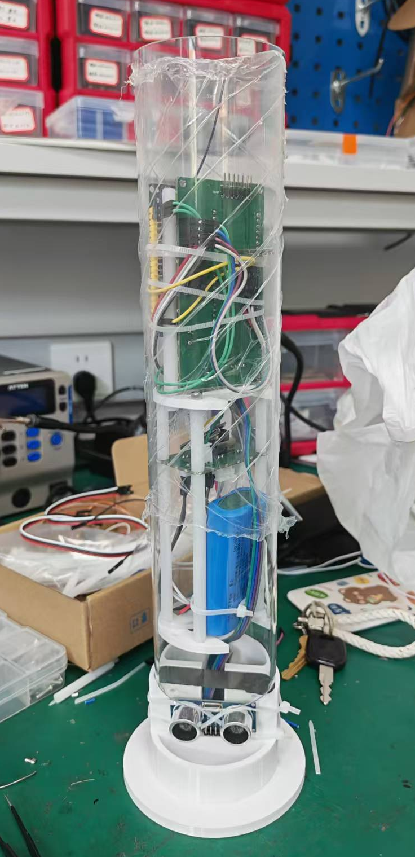
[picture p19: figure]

已实现功能：
1. 超声波三级避障 + 照度自动照明 + GPS 定位
2. SOS 按键/网页/串口触发与解除
3. OV 2640 MJPEG 图传 + 单帧抓拍
4. FreeRTOS 双核调度 + 分级告警状态机
5. 中文网页监控 + Windows 上位机（串口/图传/GPS 地图）

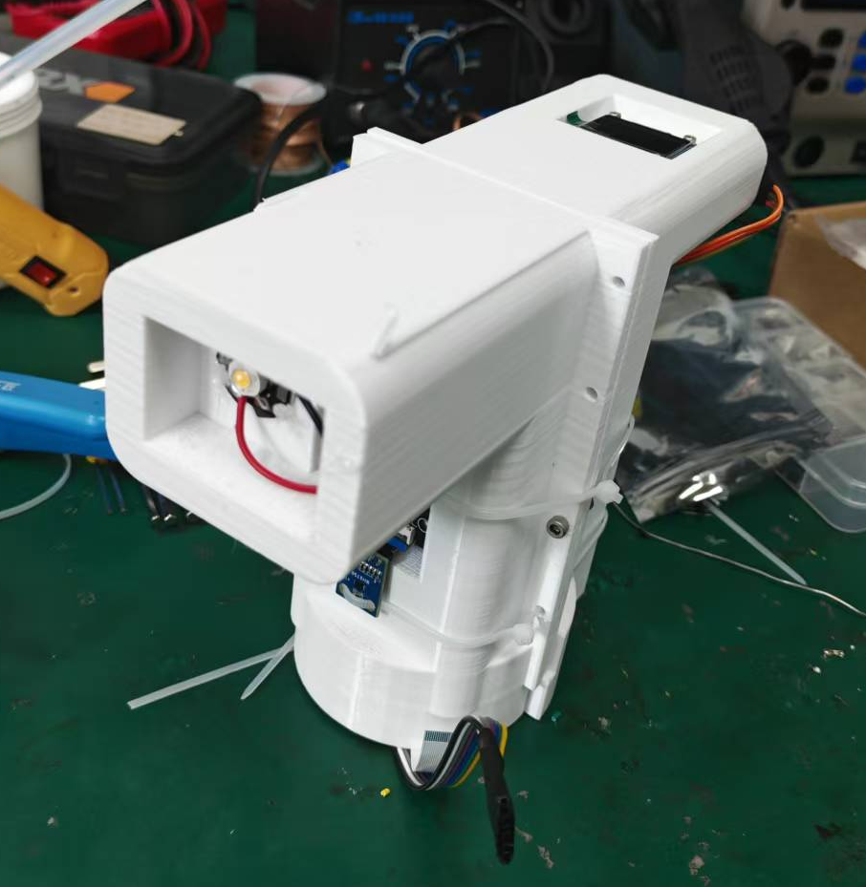
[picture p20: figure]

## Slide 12

05

当前成果-网页端展示✅

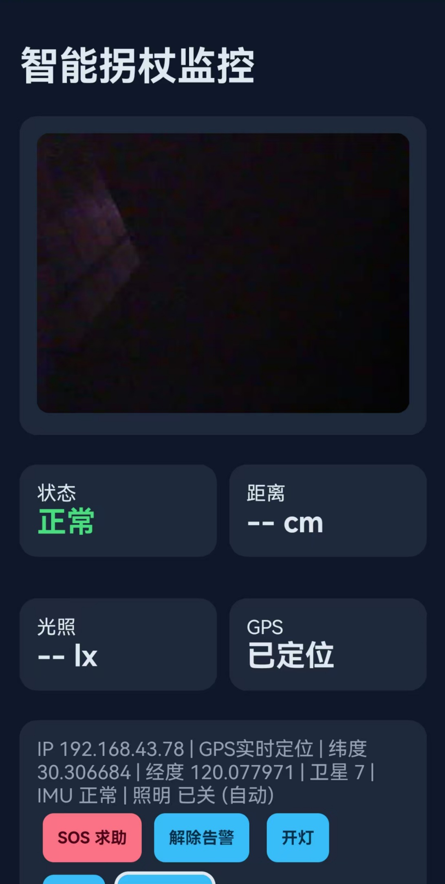
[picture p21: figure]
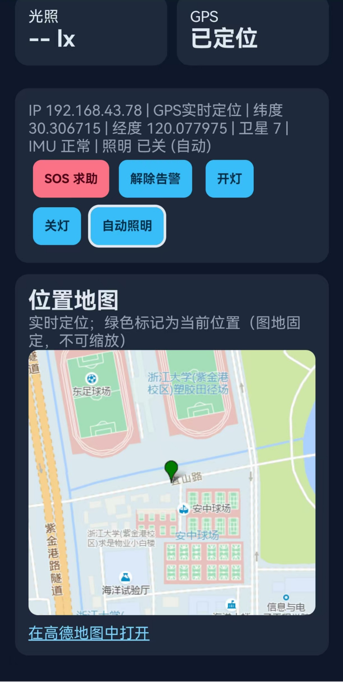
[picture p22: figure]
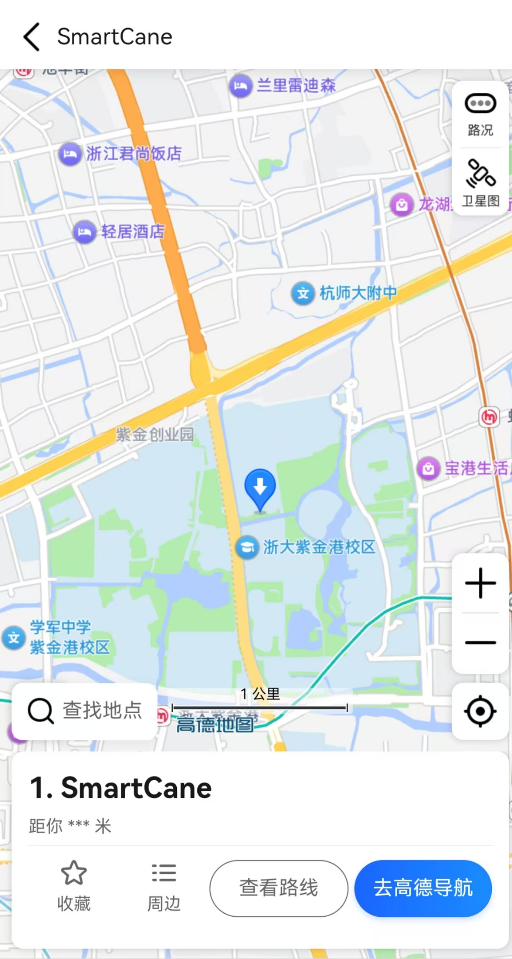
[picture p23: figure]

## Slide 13

05

当前成果-联调测试✅

上电后串口输出 I2C 扫描结果（0x23 BH1750、0x3C OLED、0x57 超声波）与各模块在线状态，确认 FreeRTOS 任务分布正确。

序号 | 操作 | 预期
1 | 障碍物 > 120 cm | NORMAL
2 | 障碍物 80/40/20 cm | CAUTION/WARNING/DANGER
3 | 逐渐移远 | +5 cm 回差后降级
4 | 遮住 BH 1750 | 低照度自动点灯
5 | 切换照明 | ON/OFF/AUTO 生效
6 | 按 SOS | 锁存 + 蜂鸣 + 图传加快
7 | CANCEL | 解除锁存
8 | 同时开视频流 | 传感器不阻塞
9 | 室外静止 | GPS 定位成功

启动自检

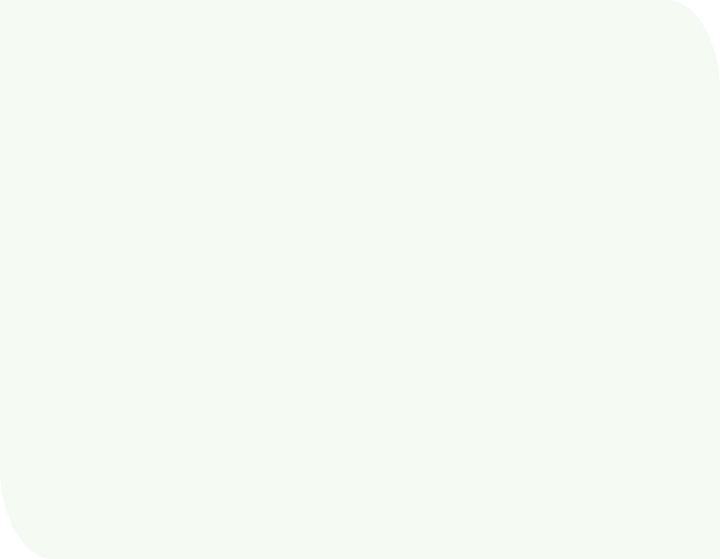
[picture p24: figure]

为验证稳定性，连续运行 ≥ 30 分钟，每 10 分钟记录距离/IMU/堆/Wi-Fi/重启状态。

分级联调

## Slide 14

06

下一阶段规划-跌倒检测📌

误报抑制

通过多场景数据训练，区分"人跌倒"与"拐杖靠墙/放下"等日常行为

召回验证

验证不同姿态、不同速度跌倒场景下的检测召回率

建立正常行走、停走、放下拐杖、靠墙、碰撞、模拟跌倒等场景的 IMU 数据集

1

2

4

3

基于实测数据校准当前估算阈值
（自由落体 ≤ 0.55 g、冲击 ≥ 2.20 g、倾角 ≥ 55°）

数据采集

阈值标定

目标：每个参数都有数据依据，正常行为误报率和模拟跌倒召回率有记录。

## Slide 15

06

下一阶段规划-提升安全性📌

自动化测试

- FallDetector 可回放 IMU 单元测试
- AlarmController 状态转移表测试
- 命令队列顺序/满队列/非法命令测试
- 状态快照并发读写测试

硬件扩展（可选增强）

- 震动马达、电池电压检测、心率血氧
- 云台舵机、4 G 通信、SD 卡存储

软件增强

- 自适应避障：从固定阈值升级为距离 + 接近速度 + TTC 综合风险判断
- 二阶段异常确认：从一次冲击即报警升级为"疑似 → 确认窗口 → 最终告警“
- 事件证据包：从状态字符串升级为可解释证据包（原因 + 时间线 + 位置 + 图片）
- 健康自检与降级：实现传感器失效时的自动提示和功能降级

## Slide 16

06

下一阶段规划-提升安全性📌

实现 TTC 风险判断、二阶段异常确认、CareEvent 证据包与传感器特征缓冲

阶段 2

完成 FreeRTOS 任务化、超声波滤波滞回与本地基本功能稳定

阶段 1

冻结并核实硬件，确认 Flash/PSRAM 容量与电源稳定性，统一型号描述

完成路由器/手机热点远程看护演示、事件上传与断网重试机制

阶段 3

有余力时训练轻量 IMU 分类器，评估震动马达、心率血氧等增强项

阶段 0

阶段 4

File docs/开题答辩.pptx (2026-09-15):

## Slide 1

基于ESP32的智能拐杖系统
嵌入式系统高级实验开题报告

小组成员：成员A、成员B、成员C
2026 / 7 / 8

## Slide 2

项目背景与目标

1

2

平台选择

3

硬件组成

4

功能和性能指标

系统设计

5

6

开发难点估计

7

预期成果及创新点

8

任务分工

目 录

CONTENTS

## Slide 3

项目背景与目标

- 随着全球人口老龄化进程加速，老年人安全问题日益凸显。在中国，60岁以上老年人口已达2.8亿，占总人口20.4%，跌倒已成为65岁以上老年人伤害死亡的首位原因。此外我国视障人士超过1700万，日常出行面临诸多挑战：40%的视障人士因害怕碰撞障碍物而减少户外活动，58%曾因跌倒或碰撞导致身体受伤。传统辅助拐杖功能单一，无法主动感知环境危险，也缺乏紧急求助机制。
- 本项目基于老年人与视障群体的实际需求，设计一套基于 ESP32 的智能拐杖系统。
- 通过超声波、IMU、GPS、光照与摄像头等模块采集外部环境与运动状态，ESP32 完成读取、判断、本地报警和图像回传。
- 关键目标：障碍物分级提醒、跌倒检测、GPS 定位、夜间示廓灯自动开启、SOS 求助、网页端状态显示与摄像头环境图传。

系统架构：
感知层 → 数据处理层 → 状态决策层 → 执行报警层 → WiFi 通信与远程看护层

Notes: 当检测到跌倒、SOS 或异常状态时，系统可立即触发蜂鸣器、震动马达和 LED 报警，并通过 WiFi 将位置信息、设备状态和现场图像回传到手机或电脑网页端，辅助家属远程判断现场情况。

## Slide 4

平台选择

项目 | 内容
主控平台 | ESP32-S3-CAM / ESP32-CAM / 带 PSRAM 的 ESP32 开发板
开发环境 | Arduino IDE / PlatformIO
编程语言 | C/C++
通信方式 | WiFi，后续可扩展 4G Cat.1
显示方式 | 手机网页端 / 电脑网页端 / 串口监视器 / OLED 可选
系统结构 | ESP32 单主控，多任务调度


选择ESP32的原因

1. 集成WiFi/蓝牙，支持远程监控与通信
2. 支持FreeRTOS多任务调度，适合并行处理传感器读取、状态判断、图传和网页服务
3. 支持摄像头与PSRAM，满足图传需求
4. 开发生态成熟，Arduino可快速完成传感器驱动、网页服务和图传功能
5. 成本低，适合本课程设计和展示

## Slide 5

硬件组成

模块 | 选型 | 作用 | 预算
主控模块 | ESP32-S3-CAM | 负责传感器采集、状态判断、WiFi 通信和摄像头图传 | 52.8元（含摄像头）
避障传感器 | HC-SR04 | 检测前方障碍物距离 | 2.65元
姿态传感器 | MPU6050 | 检测倾斜、跌倒、运动状态 | 9.5元
定位模块 | ATGM336H GPS | 获取经纬度位置 | 20元
光照检测 | BH1750 | 判断环境明暗 | 3.6元
摄像头模块 | OV2640 摄像头 | 实现环境图像采集与网页图传 | 略
本地提醒 | 蜂鸣器、震动马达、LED 示廓灯 | 避障、跌倒、SOS 等状态提醒 | 4.41元 0.8元
求助模块 | SOS 按键 | 用户主动触发紧急求助 | 4.1元
显示模块 | OLED 屏，可选 | 显示距离、姿态、GPS、系统状态 | 8.8元
供电模块 | 锂电池 + 5V/3.3V 稳压模块 | 为 ESP32 和外设供电 | 16.9+2.65+2.38元
| | | 128.59元

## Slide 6

功能与性能指标

根据距离远近提供不同强度的蜂鸣器和振动提醒
20–300 cm 测距，刷新频率 ≥ 5 Hz；
<100 cm 轻提醒，<50 cm 强提醒，<30 cm 紧急报警

🦯 分级超声波避障

判断拐杖姿态突变、倾倒或长时间异常静止，跌倒后 2 s
内触发报警并开启图传

📉 IMU跌倒检测

室外 1 Hz 更新，网页端实时显示经纬度

📍 GPS 定位

光照低于阈值自动开启 LED 示廓灯

🌙 夜间辅助

按键触发立即报警，上传 GPS 与现场图像；
不同状态对应不同报警模式

🆘 SOS 求助

QVGA/VGA 分辨率，约 5 到 10 fps；
跌倒或 SOS 时触发图像显示/拍照

📷 异常图传

通过WiFi模块连接手机或电脑网页端查看状态、GPS定位、现场图像等信息

WiFi网页显示

无线网络

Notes: WiFi 网页显示，通过wifi模块和蓝牙模块连接手机或电脑访问网页端查看状态，显示GPS定位、现场图像和设备状态等信息

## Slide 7

系统软件设计

系统采用 FreeRTOS 多任务架构：

任务 | 内容 | 核心
WiFi/Web任务 | 网页服务与数据通信 | Core0
Camera任务 | 图像采集与MJPEG传输 | Core0
Sensor任务 | 传感器数据读取 | Core1
State Machine任务 | 状态判断 | Core1
Actuator任务 | 报警控制 | Core1
Data更新任务 | 数据刷新 | 双核


采用双核任务绑定策略：
- Core0：WiFi + 图传
- Core1：传感器 + 控制逻辑
以降低图传对实时控制的影响，提高系统稳定性。

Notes: 系统基于FreeRTOS构建多任务架构，各任务之间通过消息队列进行通信，实现传感器数据采集、状态判断、报警控制和网络传输的并行处理。

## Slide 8

系统状态设计

电池电压低于阈值
提醒充电，降低图传或上传频率

低电量
状态

紧急避障状态

距离小于 30 cm
高频蜂鸣、强震动、LED 闪烁

跌倒报警状态

正常
状态

IMU 检测到倾倒或异常冲击
本地报警，网页端显示跌倒信息，开启图像回传

避障提醒状态

距离小于 100 cm
低频蜂鸣或轻微震动

用户按下 SOS 按键
立即报警，上传 GPS 和现场画面

SOS求助
状态

夜间辅助状态

光照低于设定阈值
自动开启 LED 示廓灯

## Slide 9

远程看护与图像回传设计

智能拐杖监护系统（示例）
状态：正常
距离：56 cm
姿态：正常
GPS：120.xxx
光照：较暗
SOS：无
──────────────────────
摄像头画面
──────────────────────

图像格式：JPEG(MJPEG)
分辨率：320×240
帧率：5~10 fps


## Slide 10

开发难点

IMU 跌倒误判

普通晃动或放到拐杖可能误触发
解决：采用加速度突变 + 倾角持续时间 + 静止时间联合判断。或者用ESP32 本地运行轻量分类模型，识别正常行走、静止、剧烈晃动和跌倒状态。

ESP32 资源占用较高

同时运行传感器采集、图传，资源压力较大
解决：使用双核任务绑定，将图传和传感器分开到不同核心。同时适当降低图传的分辨率和帧率

传感器数据抖动

超声波、IMU数据可能存在噪声
解决：加入滑动平均、中值滤波和阈值滞回

齿轮

还可能存在供电不稳定、摄像头图传卡顿、ESP32-CAM 引脚不足等难点

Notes: 供电不稳定：摄像头和 WiFi 工作时电流波动较大。使用独立稳压模块，保证 5V/3.3V 电源余量
摄像头图传卡顿：WiFi 环境差或图像分辨率过高。优先采用 AP 模式演示，使用 QVGA/VGA 分辨率
ESP32-CAM 引脚不足：优先选择 ESP32-S3-CAM 或合理规划串口、I2C、GPIO。或者可以考虑stm32和esp32双mcu。

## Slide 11

预期可展示效果

1. 实现障碍物检测，并根据距离进行蜂鸣器和振动分级预警，距离越近提醒越强。
2. 实现跌倒检测与 SOS 一键求助报警功能。
3. 实现环境光检测，自动控制 LED 示廓灯开关。
4. 实现网页端实时显示距离、姿态、GPS、光照及系统状态，并支持摄像头画面查看。
5. 异常情况下自动进行图像回传，实现远程环境监测。
6. OLED（或串口）实时显示系统运行状态及传感器数据。

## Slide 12

预期成果

1

实物系统
一套可运行的 ESP32 智能导行与远程看护拐杖原型


2

软件代码
传感器驱动、FreeRTOS 多任务、状态机、报警控制、WiFi 网页和摄像头图传程序

展示平台
手机端/电脑端网页显示界面

3

4

文档材料、演示视频

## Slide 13

创新点

本地提醒与网页端远程显示结合

ESP32 单主控综合设计

多传感器状态机决策

试管
正义天平
眼睛

异常触发式远程看护

可持续性

双核任务调度优化

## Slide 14

任务分工

成员B

成员A

成员C

- ESP32 网页端界面
- 摄像头图传页面
- PPT 制作
- 系统框图、流程图绘制
- 测试表格整理
- 演示视频剪辑

- ESP32 接线
- 超声波、IMU、GPS、光照、按键驱动
- 蜂鸣器、LED、震动马达控制
- 供电与结构安装

- FreeRTOS 多任务设计
- 跌倒检测算法
- 避障判断
- 状态机设计
- WiFi 数据通信
- 整体程序调试

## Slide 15

恳请老师批评指正

小组成员：成员A、成员B、成员C
2026 / 7 / 8

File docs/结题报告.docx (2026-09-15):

b浙大名标_拷贝

课程名称： | 嵌入式系统高级实验
任课教师： | 叶炜、陆玲霞
项目名称： | 基于ESP32-S3-CAM的智能看护拐杖
小组成员： | 成员A、成员B、成员C
所在专业： | 自动化（电气）
所在学院： | 电气工程学院

2026 / 09 / 12

目 录

# 第一章 项目概述

## 1.1 项目背景

跌倒一直是老年人伤害防护研究的重点，可穿戴与场景感知两条技术路线上的工作都很多。面向独居老人和出行不便人群，单纯做跌倒检测或避障还不够，把生命体征感知、求助呼叫和远程监护放到同一件随身设备上更实用。智能拐杖正好承担这个角色：靠近人的日常行走习惯，方便采集传感器数据，也能就地报警、发求助和上云。

本项目围绕“感知、决策、执行、通信”四件事做了一套基于 ESP32-S3 的智能拐杖原型：

• 感知层：九轴惯性测量单元（IMU）、血氧心率传感器（MAX30102）、环境光传感器（BH1750）、超声波测距模块、卫星定位模块；

• 决策层：FreeRTOS 双核调度下完成跌倒检测、障碍分级告警、光照控制与告警优先级仲裁；

• 执行层：蜂鸣器、照明 LED 与求救按键提供就地反馈；

• 通信层：串口上位机调试、摄像头图传、MQTT over TLS 的公网远程监护链路。

参照跌倒检测类研究，本项目的检测与告警逻辑按课程原型评估，不做医疗或人身安全认证声明。

# 第二章 项目需求与总体设计

## 2.1 功能需求

编号 | 功能 | 说明 | 验收准则
R1 | 障碍物分级告警 | 前方障碍按 100 / 50 / 30 cm 分级为 CAUTION / WARNING / DANGER，带 5 cm 回差 | 远近移动障碍时级别正确切换并能解除
R2 | 跌倒检测 | 冲击与倾斜静止双条件，或深度失重旁路；先疑似后锁存 | 正常动作不误报，受控跌倒进入 SUSPECTED_FALL 并在约 4 秒后锁存 FALL
R3 | SOS 求助 | 实体按键、网页、串口均可触发，锁存待解除 | SOS 状态可本地与远程显示，CANCEL 后恢复
R4 | 智能照明与手动控制 | 照度低于 20 lx 自动点亮；常开 / 常关 / 自动三模式 | 遮挡光照传感器能自动照明，网页与串口可切换模式
R5 | 生命体征与节律筛查 | 心率、血氧、PPG 质量与 15 秒节律特征窗口 | 稳定按压下输出有效心搏序列与节律状态
R6 | 卫星定位 | 经纬度、卫星数与最后有效定位缓存 | 室外开阔天空可获得定位并在网页显示
R7 | 摄像头图传 | 抓拍与 MJPEG 视频流，异常时提高帧率 | 局域网内可预览现场画面
R8 | 远程监护 | 设备在线、遥测、生命体征、事件经公网 MQTT 上云并实时展示 | MQTTX 能订阅到周期消息与 SOS 事件，网页能实时显示
R9 | 串口调试 | SC1 协议遥测与控制命令，IMU/PPG 高频 CSV 采集 | 上位机可采集并回放实机数据

## 2.2 非功能需求

• 实时性：IMU 实际采样约 10 Hz，跌倒状态机按 20 ms 周期更新；传感器、决策、执行、网络任务独立运行，关键告警不因其他任务阻塞；

• 可靠性：命令经 FreeRTOS 队列传递，队列满时给出明确错误码；SOS 与跌倒告警锁存，只能通过解除命令复位；

• 安全性：MQTT 使用 TLS 8883 与根证书校验，远程命令默认关闭，网页为只读监护端；固件与配置文件不携带真实凭据；

• 真实性：所有传感器数值在无效时使用 JSON null，不伪造有效数据。

## 2.3 系统设计方案

系统设计初稿如图2.1所示。


图2.1 系统设计初稿

实验在 Windows 11 + VS Code 环境下进行，固件使用 PlatformIO + Arduino 框架开发，目标板为 GOOUUU ESP32-S3-CAM（板载 OV2640 摄像头）。开发环境配置如下表所示。

项目 | 内容
操作系统 | Windows 11
开发集成环境 | VS Code + PlatformIO
目标平台 | esp32-s3-cam（ESP32-S3，8MB Flash，qio_opi）
固件框架 | Arduino 框架 + ESP-IDF 组件，含 FreeRTOS
语言 | C / C++
串口调试 | CH340 转 USB-TTL，115200 baud
上位机 | Qt（C++）采集与回放工具
远程网页 | Python Flask + Paho MQTT + SSE
公网 Broker | EMQX 云服务（MQTT 3.1.1，TLS 8883）
测试工具 | MQTTX、pytest、PlatformIO 内置测试

# 第三章 硬件设计

## 3.1 硬件总体结构

系统硬件围绕 ESP32-S3 主控展开，结构如图3.1所示。主控板为 GOOUUU ESP32-S3-CAM，板载 OV2640 摄像头与大容量 PSRAM，外接 IMU、MAX30102、BH1750、GPS 与执行器件。


图3.1 硬件总体结构

## 3.2 主控芯片与核心板

ESP32-S3 集成双核 Xtensa LX7 处理器，主频最高 240 MHz，集成 Wi-Fi 与蓝牙，提供多个硬件 I2C、UART 与并行摄像头接口。本项目利用其双核优势隔离实时传感任务与网络协议栈任务，并利用其并行相机总线直连 OV2640，从而在一颗低成本芯片上同时承载传感、决策、图传与网络服务。

核心板说明：

• 电源：USB 5 V 供电，板上稳压后为传感器与外设提供 3.3 V / 5 V；

• 存储：8MB Flash，构建结果显示 Flash 占用约 51.4%（最终固件），RAM 占用约 16.8%；

• 相机：板载 OV2640 并行接口，引脚由板卡固定不可复用。

## 3.3 传感器模块

模块 | 型号 | 接口 | 关键参数 | 用途
惯性测量 | JY901S | UART（GPIO39/38） | 9600 baud，输出九轴与欧拉角 | 跌倒检测
血氧心率 | MAX30102 | I2C（0x57） | 100 kHz，主 I2C GPIO41/42 | PPG 与节律筛查
环境光 | BH1750 | I2C（0x23） | 100 kHz | 自动照明
定位 | ATGM336H | UART（GPIO47/21） | 9600 baud，NMEA | 位置上报
摄像头 | OV2640 | 并行 + SCCB | 板载默认引脚 | 图传
超声波测距 | I2C 测距模块 | I2C（0x57） | 100 kHz | 避障测距（当前台架停用，见第七章）

## 3.4 执行与交互模块

• 蜂鸣器：GPIO1 接 MOS 管栅极，高电平响，采用非阻塞节奏提示；

• 照明 LED：GPIO14 高电平点亮，自动模式按光照阈值点亮；

• SOS 按键：GPIO40，按下为高电平，实体键带 30 ms 消抖，“按下切换”逻辑；

• OLED：I2C 0x3C（当前台架停用，见第七章）。

## 3.5 引脚与总线分配

功能 | 引脚 | 说明
I2C SDA / SCL | GPIO41 / GPIO42 | 外设 I2C 共用总线，100 kHz
IMU RX / TX | GPIO39 / GPIO38 | JY901S，9600 baud
GPS RX / TX | GPIO47 / GPIO21 | ATGM336H，9600 baud
SOS 按键 | GPIO40 | 高电平有效
蜂鸣器 | GPIO1 | MOS 管栅极，高电平响
照明 LED | GPIO14 | 高电平亮
相机总线 | 见 BoardConfig.h | 板载固定，不可复用
MAX30102 备用 I2C | GPIO2 / GPIO48 | 需要第二路 I2C 时的备用接线

I2C 总线采用 100 kHz 标准模式。MAX30102 与超声波测距模块的 I2C 地址同为 0x57，为避免混淆，当前台架将超声波与 OLED 停用，MAX30102 独占主 I2C 总线；完整方案需引入 I2C 多路复用器或独立软件 I2C。

# 第四章 软件设计

## 4.1 软件总体框架

软件基于 FreeRTOS[6] 多任务调度，利用 ESP32-S3 双核划分实时与网络任务。任务划分如下表所示。

核心 | 任务 | 周期 | 职责
Core 1 | SensorTask | 10 ms | 采集 IMU、GPS、测距、光照与 SOS
Core 1 | DecisionTask | 20 ms | 跌倒检测、避障分级、请求优先级仲裁
Core 1 | ActuatorTask | 10 ms | 蜂鸣器、照明 LED（执行器唯一写入者）
Core 0 | NetworkTask | 20 ms | Wi-Fi 连接维护、状态发布
Core 0 | TelemetryTask | 10 ms | SC1 串口遥测与控制命令处理

任务间通过 FreeRTOS 队列交互，避免共享可变状态直接跨线程访问。主要队列配置如下：

队列 | 长度 | 语义
SensorSnapshotQueue | 1 | 覆盖旧帧，仅保留最新传感快照
ControlCommandQueue | 12 | 按键、网页、串口命令统一入队
ActuatorIntentQueue | 1 | 覆盖旧值，执行器最新意图
imuDebugQueue | 48 | IMU 高频 CSV 调试数据

传感器 I/O 与决策在 Core 1 运行，ESP32 的 Wi-Fi / HTTP 协议栈在 Core 0 被服务，从而避免网络中断影响本地报警。

## 4.2 共享数据模型

驱动层、控制层与通信层通过统一的原始数据契约 SensorSnapshot 共享数据。无效浮点字段保持 NAN，禁止当作 0 使用；valid 仅表示当前驱动已得到有效帧。核心数据模型如下：

struct SensorSnapshot {
float distanceCm; // 前方障碍距离（无效为 NAN）
float lux; // 环境照度
ImuReading imu; // 九轴 + 欧拉角 + 合加速度
GpsReading gps; // 当前定位；失星后 valid=false
GpsReading lastValidGps; // 本次上电最后一次有效定位
VitalsReading vitals; // 心率/血氧/节律筛查结果
};

struct ActuatorIntent {
SensorSnapshot sensors;
AlarmKind alarm; // NONE / CAUTION / WARNING / DANGER / SUSPECTED_FALL / FALL / SOS
bool buzzerOn, lightOn;
bool sosLatched, suspectedFall, fallLatched;
int8_t manualLightMode; // -1 自动 / 0 关 / 1 开
bool incidentActive; // 异常事件期间提高图传帧率
};

ActuatorIntent 是值对象，可跨队列传递而不共享可变的 GPIO 状态。

## 4.3 请求优先级与告警逻辑

系统对告警按以下优先级仲裁：

SOS > FALL > DANGER(<30 cm) > WARNING(<50 cm) > CAUTION(<100 cm) > NORMAL

• SOS 与跌倒告警锁存，仅可经网页 POST /api/cancel、串口 SC1 CMD CANCEL 或实体键解除；

• 障碍物告警只依赖最新有效测距，数据失效后自动退出障碍物状态，避免持续报警；

• 蜂鸣器与 LED 使用非阻塞节奏（不调用 delay()），距离越近提示越密，危险、SOS 与跌倒时 LED 闪烁。

## 4.4 跌倒检测算法

跌倒检测采用“候选 + 冲击/失重 + 倾斜静止保持”的双路径状态机，仅消费有效的 JY901S 快照。两条路径的判定规则如下：

1. 严格路径：在 2.0 秒窗口内以低重力或冲击进入候选，随后必须采到不低于 2.20 g 的冲击，再要求横滚或俯仰倾角至少 55°，合角速度不超过 45°/s，并持续 600 ms；

2. 深度失重路径：若采到深度低重力（不超过 0.40 g），即使约 10 Hz 数据漏掉冲击峰值，也可在相同倾斜与静止条件下持续 1200 ms 后进入疑似状态。

任一路径确认后先进入 SUSPECTED_FALL，4 秒内未取消才锁存为 FALL；取消后 3 秒内不重复触发。整个过程基于时间戳而非 delay()，保证其他 FreeRTOS 任务继续运行。冻结参数如下表所示，集中于 src/config/UserConfig.h，且存在编译期断言检查参数合理性。

参数 | 冻结值 | 作用
FALL_FREE_FALL_G | 0.55 g | 普通低重力候选入口
FALL_DEEP_FREE_FALL_G | 0.40 g | 未采到冲击峰值时的深度失重入口
FALL_IMPACT_G | 2.20 g | 严格路径冲击阈值
FALL_TILT_DEG | 55° | 横滚/俯仰倾斜阈值
FALL_STILL_GYRO_DPS | 45°/s | 倾倒后静止角速度上限
FALL_TILT_HOLD_MS | 600 ms | 严格路径持续保持时间
FALL_DEEP_TILT_HOLD_MS | 1200 ms | 深度失重路径持续保持时间
FALL_SEQUENCE_WINDOW_MS | 2000 ms | 候选动作总窗口
SUSPECTED_FALL_CONFIRM_MS | 4000 ms | 疑似转锁存等待时间
FALL_CANCEL_COOLDOWN_MS | 3000 ms | 取消后的重复触发抑制

冻结参数后的独立验收共取得 17 份原始记录，其中 1 份后向倾倒记录因动作在完成前停止被判无效并原样保留，随后重新完成后向试验，最终有效验收集为 12 组正常动作与 4 组四方向模拟跌倒。最终有效集混淆矩阵如下表所示。

| 实际跌倒 | 实际正常
检出跌倒 | TP=4 | FP=0
未检出 | FN=0 | TN=12

分析结论：

• 正常动作 12 次全部未进入 SUSPECTED_FALL，误报率 0%；快速行走虽曾满足普通低重力候选，但因缺少冲击与倾斜静止保持而未误报；

• 四方向模拟跌倒全部检出，召回率 100%；前向试验走严格路径并在约 4 秒后锁存 FALL，其余场景分别经严格路径与深度失重路径触发；

• 该结果仅在受控场景、当前安装方式下成立，表示为本轮受控场景通过率100%，不上升为面向真实人群的准确率或安全认证结论。

## 4.5 生命体征与节律筛查算法

MAX30102 以 100 kHz I2C 接入主总线。软件按以下数据链处理：

1. FIFO 读取：每次最多取出 6 个 RED/IR 样本，补偿帧序号并统计丢帧；

2. 手指检测：以 IR 强度阈值判断手指是否按压，无手指时不输出心率；

3. 滤波与峰值检测：局部极大值同时满足幅度阈值与相对谷值突出度阈值；近期 IBI 稳定时启用有上限的自适应不应期，而突出度足够强的提前心搏仍可通过，避免机械抹平真实不规则性；

4. 心率血氧原型估算：HR 显示使用最近 IBI 中位数，SpO2 采用课程原型公式进行趋势估算（非医疗精度）；长间隔后清空旧 IBI 窗口重新积累，连续约 3 秒无新心搏则旧 HR 立即失效；

5. 节律筛查：以 15 秒稳定 PPG 窗口提取 IBI 均值、标准差（SDNN）、变异系数（CV）、RMSSD 与 pNN50 等特征，由端侧基线分类器给出 NORMAL / IRREGULAR / SUSPECTED_AF 等状态；要求至少 12 个有效 IBI、信号质量不低于 0.70，并只在拐杖静止（角速度不高于 20°/s、加速度变化不高于 0.18 g）且运动后静止一段时间后才参与判定；疑似节律异常需连续多个窗口确认才会产生远程序列提醒。

当前节律权重是未校准的端侧集成基线（model_calibrated=false），本实验只做正常负样本、接触压力、运动伪影与回归类测试，不作房颤诊断或医疗器械精度声明。

最终验收 P041～P043 关键指标如下表所示。

指标 | 数值
有效 IBI 总数 | 243
短 IBI（<500 ms） | 0
长 IBI（>1200 ms） | 0
IBI 变异系数（CV） | 0.070 / 0.058 / 0.100
端侧节律推理 | 29 次，全部 NORMAL
推理耗时 | 平均 65.6 μs，P95 95.4 μs，最大 106 μs

分析结论：

• 25 Hz FIFO 全记录零丢帧说明采集链路稳定，finish 与序号机制有效；

• 短/长 IBI 均为 0、CV 处于 0.058～0.100 区间，表明三份稳定按压记录的心博序列连续且均匀；

• P043 稳定段有效率为 57.8%，系统在接触不佳时主动作废旧 HR，按降级样本处理；

• 由于本轮没有标准心率/血氧仪与 ECG 参考标签，本报告不报告 MAE、Bias 等医疗级精度指标。

## 4.6 MQTT 远程通信设计

远程通信采用 MQTT 3.1.1 over TLS（端口 8883），Topic 根路径为 smartcane/device01。设计要点如下：

• 传输安全：TLS + 根证书校验，账号密码仅存于设备配置与服务器环境变量，固件交付不携带真实凭据；

• 订阅模式：上行五类 Topic（presence / telemetry / vitals / gps / event），下行 command 默认关闭，网页为只读监护端；

• QoS：连接状态与事件使用 QoS 1，周期遥测使用 QoS 0；presence 使用 retained 消息以便新订阅者获得当前在线状态；

• 在线判定：网页仅在 Broker 已连接、retained presence 为 online 且最近一次 telemetry 在 15 秒内时显示设备在线，避免 Broker 在线但设备失联时误报；

• 诚实性：无定位时 gps 坐标为 null，节律未校准时 model_calibrated=false 照实上报。

图4.2给出完整的公网数据链路。


图4.2 MQTT 公网数据链路

Topic 与数据格式定义如下表所示。

Topic | 方向 | 内容 | 周期 / QoS | Retain
.../presence | 设备→云端 | online / offline | 连接状态变化，QoS 1 | 是
.../telemetry | 设备→云端 | 报警、传感器在线、RSSI、运行时间 | 约 5 s，QoS 0 | 否
.../vitals | 设备→云端 | 心率、血氧、PPG 质量、节律摘要 | 约 5 s，QoS 0 | 否
.../gps | 设备→云端 | 定位来源、经纬度、卫星数 | 约 10 s，QoS 0 | 否
.../event | 设备→云端 | SOS、疑似跌倒、跌倒、节律提醒 | 状态变化即时，QoS 1 | 否
.../command | 云端→设备 | 远程命令 | QoS 1（默认关闭） | 否

链路验证证据如下表所示。网页正常状态显示心率 78 bpm、血氧 99%、PPG 质量 96%，说明 telemetry 与 vitals 两条周期链路经公网 Broker 到达网页。SOS 状态截图证明 smartcane/device01/event 收到 event=SOS 且 QoS 为 1。

验收项 | 结论 | 证据
TLS 8883 配置 | 已验证 | MQTTX 配置截图、固件连接日志
Broker 连接 | 已验证 | 串口日志可见 CONNECTING→ONLINE
周期 telemetry/vitals/gps | 已验证 | MQTTX 周期消息截图
SOS 事件 QoS 1 | 已验证 | MQTTX SOS 截图
网页正常/SOS 显示 | 已验证 | 正常状态与 SOS 状态截图
远程命令关闭 | 已核对 | 固件配置为 false，网页无控制入口

# 第五章 具体制作与实现

## 5.1 硬件搭建

按照第三章的引脚分配完成主控板与各传感器的接线：JY901S 接 GPIO39/38，ATGM336H 接 GPIO47/21，MAX30102 接主 I2C（GPIO41/42），蜂鸣器、照明 LED 与 SOS 按键分别接 GPIO1、GPIO14 与 GPIO40。

## 5.2 避障告警实现

避障功能在 DecisionTask 中按照 100 / 50 / 30 cm 三级阈值输出 CAUTION / WARNING / DANGER，并使用 5 cm 回差防止测量抖动导致的反复报警；测距值由传感器任务按 220 ms 周期更新，蜂鸣器节奏随距离自动加密。图5.1为现场避障功能联调场景，图5.2为上位机实时页面。


图5.1 避障检测现场


图5.2 避障检测页面

## 5.3 智能照明实现

BH1750 以 500 ms 周期采集环境照度，照度低于 20 lx 时自动点亮照明 LED；网页 GET /api/light?mode=on|off|auto 与串口 SC1 CMD LIGHT ... 可切换常开、常关与自动。图5.3为光照检测结果。


图5.3 照明检测

## 5.4 远程图传实现

摄像头服务提供 GET /capture 抓拍与 :81/stream MJPEG 视频流。正常状态帧间隔限制为 150 ms；SOS 与跌倒锁存后取消限流，让看护端优先取得现场画面。图5.4为远程图传的实际画面。


图5.4 远程图传

## 5.5 远程监护网页实现

远程监护网页为 Python Flask + Paho MQTT + SSE 架构，后端通过 MQTT over TLS 订阅 smartcane/device01/#，浏览器通过 HTTP 页面与 SSE 实时查看状态。网页只读，无远程控制入口；MQTT 密码只存在服务器环境变量，不会发送到浏览器。桌面端与移动端界面如图5.5、图5.6所示。


图5.5 远程监护网页桌面端


图5.6 远程监护网页移动端

## 5.6 串口上位机实现

Qt 上位机通过 USB-TTL 接收固件的 SC1 协议遥测，并支持 SC1 CMD IMU STREAM ON 开启 JY901S 高频 CSV 数据流用于跌倒标定，以及 SC1 CMD IMU STREAM OFF 关闭。跌倒检测、避障决策始终运行在 ESP32 上，Qt 只记录固件输出、派生量与判定过程，不在电脑端替代实时报警。

# 第六章 调试过程

## 6.1 IMU 跌倒检测调试

IMU 调试共经历四个阶段，累计 65 份采集文件参与分析：

阶段 | 文件数 | 问题与结论
第1轮 | 16 | 初始场景采集，12 个正常场景与 4 个方向倾倒
第2轮 | 16 | 重复动作暴露漏检，发现约 10 Hz 下冲击峰值可能漏采
第3轮 | 16 | 双路径候选参数验证，发现前向跌倒最低加速度 0.3823 g，推动深度阈值冻结为 0.40 g
第4轮 | 17 | 冻结参数独立验收，16 条有效记录通过，1 条中止记录保留并重测

前三轮共 48 条记录参与参数分析，最终参数对前三轮离线重放结果为 12 次模拟跌倒全部检出、36 次正常动作全部未误报；包含第4轮 16 条有效记录在内，共 16 次模拟跌倒全部检出、48 次正常动作全部未误报。

第1轮采集的正常场景与第3、4轮的跌倒触发记录如图6.1至图6.4所示。


图6.1 正常上台阶 图6.2 正常放下


图6.3 前向跌倒触发 图6.4 后向跌倒触发

第4轮冻结参数后的独立验收中，跌倒检测与跌倒报警的实际页面如图6.5、图6.6所示。


图6.5 跌倒检测


图6.6 跌倒报警

## 6.2 MAX30102 生命体征与节律筛查调试

调试保存了 43 份原始 PPG 记录、59098 个样本、总时长 2365.49 秒，全部保持 25 Hz 有效 FIFO 输出率，序号丢帧与 FIFO 溢出均为 0，最大样本间隔 50 ms。三个阶段的任务如下：

阶段 | 文件 | 主要任务
第1轮 | P001～P011 | 空载、稳定覆盖、重复放指、压力、运动、环境光与恢复试验
第2轮 | P012～P040 | 覆盖、压力、模块运动和节律窗口的重复性补测
第3轮 | P041～P043 | 峰值突出度、自适应不应期与心搏新鲜度保护修改后的最终验收

峰值算法经多轮迭代后收敛：突出度阈值抑制了伪峰，自适应不应期避免生理性不规则被机械抹平，心搏新鲜度保护机制在连续约 3 秒无新心搏时主动使旧 HR 失效，从而在接触不佳时依然诚实输出。正常按压时的原始 PPG 波形如图6.7所示。


图6.7 正常按压 PPG 波形

最终验收阶段的稳定节律窗口波形与血氧检测页面如图6.8、图6.9所示。


图6.8 最终节律稳定窗口波形

图6.9 血氧检测

## 6.3 MQTT 公网链路调试

MQTT 调试完成后端到端打通了“ESP32-S3-CAM → MQTT over TLS → MQTTX / 远程监护网页”链路。调试过程中依次验证了 TLS 8883 连接、NTP 校时、五类 Topic 周期发布、presence 在线判定与 SOS 事件 QoS 1 发布，网页可从公网 MQTT 实时显示正常与求助状态。2026-08-31 11:24—11:51 的原始串口日志记录了 MQTT 从 CONNECTING 进入 ONLINE 的完整过程。MQTTX 的 TLS 连接配置如图6.10所示。


图6.10 MQTTX TLS 连接配置

MQTTX 周期消息接收与 SOS 事件 QoS 1 发布的验收截图如图6.11、图6.12所示。


图6.11 MQTTX 周期消息接收


图6.12 MQTTX SOS 事件 QoS1

# 第七章 问题与解决方法

问题 | 原因 | 解决方法
MAX30102 与超声波测距模块 I2C 地址同为 0x57，两模块共存时报错 | I2C 设备地址冲突 | 当前台架停用超声波与 OLED，MAX30102 独占主 I2C 总线；完整方案需 I2C 多路复用器或独立软件 I2C
约 10 Hz JY901S 采样可能漏掉冲击峰值，导致严格路径漏检 | 采样率低、瞬态冲击事件窗口短 | 增加深度失重旁路路径（不高于 0.40 g 时允许 1200 ms 深度保持）
前向倾倒最低加速度仅 0.3823 g | 倾倒过程以失重为主、冲击不显著 | 第三轮实测驱动深度阈值冻结为 0.40 g
快速行走等动作进入低重力候选但不应报警 | 单条件触发过宽 | 采用“冲击或失重 + 倾斜 ≥55° + 角速度 ≤45°/s + 持续保持”组合条件
峰值检测出现伪峰与漏峰 | 单幅度阈值不稳定、生理性不规则易被过滤 | 引入突出度阈值、自适应不应期与心搏新鲜度保护
P043 稳定段有效心率仅 57.8% | 接触不佳、心搏不连续 | 主动使旧 HR 失效并降级为安全样本，不冒充有效测量
公网网页曾因 Broker 在线但设备失联而显示正常 | 在线判定只依赖 Broker 连接 | 增加 retained presence 与 telemetry 15 秒新鲜度双重条件
串口日志末尾出现“拒绝访问” | 电脑端 TTL 串口被其他程序占用 | 判定为上位机串口竞争而非设备离线，恢复独占连接后日志正常
摄像头开启时偶发重启 | 5 V 电源瞬态电流不足 | 优先检查供电与 USB 线，不降低 FreeRTOS 任务优先级
室内 GPS 无法定位 | 室内无卫星视野属正常现象 | 移到开阔天空测试；无定位时保留最后有效定位缓存

# 第八章 项目总结

## 8.1 完成情况

本项目完成了基于 ESP32-S3 的智能拐杖系统设计与实现，相关模块在验证数据上达到下表所示结果：

子项目 | 主要交付 | 关键结果
IMU 跌倒检测 | 双路径状态机 + 冻结参数 | 16 条有效记录：4/4 检出、12 次正常 0 误报；约 4 秒锁存验证通过
MAX30102 生命体征 | PPG 数据链 + 节律筛查 | 43 份记录零丢帧；243 个有效 IBI；29 次推理全部正常
MQTT 远程监护 | TLS 链路 + 只读网页 | 五类 Topic 打通；SOS QoS 1 实测；网页实时显示正常/求助状态

系统摆脱了单模块演示，形成了“感知—决策—执行—通信”一体化闭环，固件、上位机与网页均可运行，全部数据与截图可用于复现审计。

## 8.2 局限与后续工作

• 节律权重为未校准基线（model_calibrated=false），需以 ECG 参考数据替换权重并通过最终设备 2~3 组正常/静止 30~60 秒记录复核后才能校准；

• 避障功能在完整方案中依赖 I2C 多路复用器解决 0x57 地址冲突，当前台架未联调超声波；

• 公网链路尚需补做跨运营商、强制断网重连、遗嘱离线、FALL 事件与长时间稳定性测试；

• 跌倒阈值面向本机受控场景冻结，使用前应按本机实测数据集再次复核，且不用于医疗或人身安全声明。

# 第九章 分工

成员A：

在本项目中，我主要负责智能拐杖的硬件系统设计与搭建、传感器驱动与测试以及整机联调。硬件方面，我根据拐杖内部空间和整体长度限制，自主设计了用于连接各功能板的 PCB 载板，实现三块主要电路板之间的集中连接，减少布线复杂度，使整体结构更加紧凑。同时，我结合实际舱体尺寸自主完成了部分 3D 结构设计，在舱内设计支撑、限位和固定结构，用于安装和固定 PCB，避免板卡晃动，并保证各模块能够在有限空间内合理排布。在软件测试方面，我主要完成 JY901S 九轴 IMU 和 MAX30102 心率血氧传感器的驱动与通信调试。其中 IMU 工作主要集中在后期跌倒检测功能的实验与标定，通过采集正常行走、坐下、起身、弯腰及不同方向跌倒等多种动作数据，对加速度、角速度和姿态变化进行分析，并据此反复调整跌倒检测阈值；心率血氧部分主要负责实际测量与稳定性测试。此外，我还独立开发了传感器调试上位机，用于实时接收、显示和观察 IMU 等传感器数据，提高动作分析和参数标定效率。

成员B：

在项目初期，我主要负责前期立项准备和立项答辩展示，并参与项目整体方案的讨论与规划，为后续功能开发和系统实现做好准备；在项目中期，我主要负责基础功能开发、调试以及局域网监控系统的实现。我完成了超声波避障、BH1750光照检测与自动照明、SOS按键、蜂鸣器与LED告警、OLED显示、摄像头图传和GPS定位等功能的代码开发，实现了FreeRTOS多任务分工，并通过串口、网页监控和实物测试进行调试。同时，我完成了高德地图Web服务的配置，将GPS定位结果直观展示在网页中；实现了局域网监控网页，对告警状态、距离、光照、GPS、传感器状态和摄像头画面等信息进行展示，并加入灯光控制和告警解除等交互功能。此外，我还完成了初步的IMU跌倒检测功能开发与测试，并根据实际动作数据调整检测阈值；在项目后期，我主要负责生命体征检测、跌倒检测算法优化、异常节律筛查以及公网监控系统的开发。我完成了优化后的IMU跌倒检测算法，加入深低重力检测、疑似跌倒确认、用户取消和告警锁存等机制；完成了MAX30102心率、血氧及PPG信号采集和处理，实现了节律特征提取与异常倾向筛查。我完成了基于MIMIC PERform AF数据的TinyML轻量级模型训练、测试、量化及ESP32端部署，实现异常节律预筛。在此基础上，我完成了ESP32、MQTT、阿里云服务器与亲属端浏览器之间的公网通信链路，并开发了公网只读监控网页，实现对告警状态、生命体征、GPS、设备在线状态及传感器状态等信息的远程查看。最后，我参与了项目结题答辩与实物展示。

成员C：

在本项目中，我主要负责项目过程中的文档整理、汇报材料制作以及结题报告撰写等工作。我前期参与项目选题的讨论与确定，结合小组成员的意见，对智能拐杖的整体功能和项目实施思路进行梳理，并协助整理相关资料。项目推进过程中，主要负责开题、中期和结题答辩所需 PPT 的制作，根据项目进展整理系统功能、技术路线、实现过程和阶段性成果，并通过流程图、系统框图等形式对项目的整体设计和工作流程进行直观展示。同时，配合组员收集、整理项目开发过程中的相关材料，协助完善汇报内容。在项目后期，我主要负责结题报告的撰写与整理，对项目的设计思路、制作过程、功能实现、调试情况和实验结果等内容进行汇总，结合组员提供的技术资料完成报告初稿，并根据项目实际进展进行修改和完善，协助保证项目能够按时完成。

# 第十章 体会

成员A：

通过本次智能拐杖项目，我对嵌入式产品从电路、结构、软件到整机集成的完整开发过程有了更深入的认识。项目中比较明显的一点是，真正的硬件开发并不只是完成电路连接，而需要同时考虑电气连接、空间尺寸、机械固定、布线方式以及后期调试等工程问题。例如，为了满足拐杖细长结构的尺寸限制，我需要重新规划多块电路板之间的连接方式，通过设计 PCB 载板减少飞线，并进一步结合 3D 结构设计解决舱内支撑和板卡固定问题，这让我体会到电子设计与机械结构设计之间需要高度配合。另一方面，在 IMU 跌倒检测调试中，我也认识到算法阈值不能仅依据理论设定，而必须通过真实动作数据反复测试和标定；心率血氧模块同样会受到佩戴方式和信号质量等实际因素影响。因此，一个功能最终能否稳定运行，往往取决于大量实验、调试和工程细节。通过本项目，我不仅提升了 PCB 设计、3D 结构设计、传感器驱动、串口通信和上位机开发能力，也建立了从硬件设计、结构实现到数据测试和整机验证的完整工程开发思路。

成员B：

本次嵌入式高级实验训练让我系统性地接触了一个独立项目的立项、开发、调试和结项完整过程，在这期间印象最深的不是开发写出某个代码，而是在初次代码的基础上上传到单片机进行反复调试最后功能出来的一瞬間。在这个过程我们普遍都借助了AI帮助编写代码，但AI不是万能的，更多的显示情况需要人发挥主观能动性实现。AI不可能帮助我们接线，不可能帮助我们申请公网，也不可能帮助我们连上手机进行调试，至少现在不行。在这个过程里最让我感到陌生的环节当属公网的实现，由于对互联网协议和话题相关的不熟悉，我在这块花了大把时间找教程和尝试。最后借助AI的操作指南和网上的教程，我成功在阿里云上开通了一个服务器并部署了公网。通过本项目，我认识到智能硬件开发并不是简单地把多个传感器连接起来，而是要同时处理接线、通信协议、任务调度、状态优先级、网络安全和数据可信度等问题。这次实践提升了我的系统集成、调试分析、团队协作和工程边界意识。

成员C：

由于我目前处于毕业班阶段，培养方案临时调整，加上个人需要进行实习，我在项目开展期间面临一定的时间安排困难，无法像其他组员一样长期到场参与实验和实物调试，对此也希望老师能够予以理解。尽管受到客观条件的限制，我仍积极与组员保持沟通，及时了解项目进展，认真完成PPT制作、资料整理、流程图和系统框图绘制以及结题报告撰写等工作，合理协调实习与课程任务，没有因个人原因影响小组整体进度。通过本次项目，我对嵌入式系统从选题、方案设计到功能开发、调试和结题的完整过程有了更加系统的认识。虽然我主要负责文档整理和成果展示，没有直接参与大量的硬件搭建与程序调试，但通过梳理项目资料和撰写报告，我也加深了对智能拐杖整体设计与实现思路的理解。同时，我认识到一个完整的工程项目不仅需要技术实现，也离不开良好的团队沟通、任务协作和成果总结，这些经历也提升了我的组织协调和项目总结能力。

# 参考文献

[1] ESPRESSIF. 乐鑫科技. ESP32-S3 技术参考手册（ESP32-S3 Technical Reference Manual，V1.8）[EB/OL]. https://www.espressif.com/documentation/esp32-s3_technical_reference_manual_en.pdf.

[2] ESPRESSIF. 乐鑫科技. ESP32-S3 系列芯片数据手册（ESP32-S3 Series Datasheet，V2.2）[EB/OL]. https://www.espressif.com/sites/default/files/documentation/esp32-s3_datasheet_en.pdf.

[3] ANALOG DEVICES. MAX30102 High-Sensitivity Pulse Oximeter and Heart-Rate Sensor for Wearable Health 数据手册（Datasheet）[EB/OL]. https://www.analog.com/media/en/technical-documentation/data-sheets/MAX30102.pdf.

[4] OMNIVISION TECHNOLOGIES. OV2640 Color CMOS UXGA (2.0 MegaPixel) CAMERACHIP 数据手册（Datasheet，V2.2）[EB/OL]. https://uctronics.com/download/OV2640_DS.pdf.

[5] Amazon Web Services. FreeRTOS 官方文档（FreeRTOS Documentation）[EB/OL]. https://www.freertos.org/Documentation/00-Overview.

[6] RAMACHANDRAN A，KARUPPIAH A. A Survey on Recent Advances in Wearable Fall Detection Systems[J]. BioMed Research International，2020，2020：2167160. DOI: 10.1155/2020/2167160.

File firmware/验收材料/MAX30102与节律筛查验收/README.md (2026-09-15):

# 智能拐杖 MAX30102 与节律筛查验收说明

## 1. 验收结论

本目录归档了 MAX30102 接入、RED/IR FIFO 原始数据采集、手指检测、滤波与峰值检测、
HR/SpO₂ 原型估算、SQI 质量门控、15 秒节律特征窗口、端侧基线分类器和 Qt 可视化采集
工具的调试材料。

本地调试共保存 43 份原始 PPG 记录、59098 个样本，总记录时长 2365.49 秒（约
39.42 分钟）。全部记录保持 25 Hz 有效 FIFO 输出率，序号丢帧为 0，FIFO 溢出为 0，
最大样本间隔为 50 ms。

峰值算法修改后的最终验收 P041～P043 共得到 243 个有效 IBI：

- 小于 500 ms 的短 IBI：0；
- 大于 1200 ms 的长 IBI：0；
- IBI 变异系数分别为 0.070、0.058、0.100；
- 共形成 29 次端侧节律推理，29 次均为 `NORMAL`；
- `IRREGULAR`、`INCONCLUSIVE`、`SUSPECTED_AF` 均为 0；
- 推理耗时平均 65.6 μs，P95 为 95.4 μs，最大 106 μs。

据此，当前实现满足课程设计/工程原型的本地 PPG 采集、质量控制和节律筛查数据链交付
要求。P043 的稳定段有效率为 57.8%，但系统在心搏不连续时主动使旧 HR 失效，没有用
陈旧值冒充有效测量，因此作为安全降级样本保留。

## 2. 结论边界

本轮没有标准心率/血氧仪，也没有 ECG 参考标签，因此：

- 不报告 HR/SpO₂ 的 MAE、Bias、RMSE 或医疗级精度；
- 当前 SpO₂ 公式仅为课程原型趋势估算；
- 当前节律权重是未校准的端侧集成基线，`model_calibrated=false`；
- 本地数据只用于正常负样本、接触压力、运动伪影和回归测试，不能当作房颤真实标签；
- 不能据此声称具有房颤诊断能力或医疗器械性能。

## 3. 调试阶段

| 阶段 | 文件 | 主要任务 |
|---|---:|---|
| 第1轮 | P001～P011 | 空载、稳定覆盖、重复放指、压力、运动、环境光、运动后恢复和节律窗口 |
| 第2轮 | P012～P040 | 稳定覆盖、压力、模块运动和节律窗口的重复性补测 |
| 第3轮 | P041～P043 | 峰值突出度、自适应不应期和心搏新鲜度保护修改后的最终验收 |

第2轮 P029～P035 的历史标签为 `cane_motion`，实际操作是移动 MAX30102 模块而没有
移动 IMU，故应解释为 PPG 模块/接触运动伪影，不作为 IMU 运动抑制的重复性证据。

## 4. 最终算法修改

最终实现见 `03-固件关键代码/VitalsProcessor.cpp`：

1. 局部极大值除幅度阈值外，还必须满足相对上一谷值的突出度阈值；
2. 近期 IBI 稳定时启用有上限的自适应不应期；
3. 突出度足够强的提前心搏仍可通过，避免机械抹平真实不规则性；
4. HR 显示使用最近 IBI 中位数，节律特征仍使用未平滑的有效 IBI 序列；
5. 长间隔后清空旧 IBI 窗口，重新积累连续心搏；
6. 连续约 3 秒没有新有效心搏时，旧 HR 立即失效。

## 5. 目录结构

```text
MAX30102与节律筛查验收/
├─ 01-采集数据/                 P001～P043 原始 CSV 与 trials.csv
├─ 02-验收截图/                 Qt PPG 波形和最终节律窗口截图
├─ 03-固件关键代码/             MAX30102、PPG处理、节律分类和串口协议代码
├─ 04-Qt上位机采集代码/         PPG采集、绘图、协议解析及测试
├─ 05-调试与验收文档/           指南、分析、最终结果和线上训练交接
├─ 06-最终固件与构建记录/       firmware.bin、platformio.ini 和构建记录
├─ README.md
└─ SHA256SUMS.txt
```

## 6. 快速复核入口

1. 先阅读 `05-调试与验收文档/最终验收结果.md`；
2. 查看 `02-验收截图/02-最终节律稳定窗口波形.png`；
3. 使用 `01-采集数据/trials.csv` 检索全部试验；
4. 最终独立验证原始数据位于 `01-采集数据/第3轮-算法修改后最终验收-P041至P043/`；
5. 固件实现位于 `03-固件关键代码/VitalsProcessor.cpp`；
6. 后续训练任务见 `05-调试与验收文档/线上模型训练交接.md`。

## 7. 构建状态

- 固件构建：成功；
- RAM：55308 / 327680 bytes（16.9%）；
- Flash：1012877 / 1966080 bytes（51.5%）；
- Qt 自动测试：21 项全部通过；
- 最终二进制：`06-最终固件与构建记录/SmartCane-MAX30102-final.bin`。

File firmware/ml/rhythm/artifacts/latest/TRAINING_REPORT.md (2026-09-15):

# 智能拐杖异常节律候选模型训练报告

> 本模型只用于课程项目的异常节律筛查，不能诊断房颤，也不能替代心电图和医生判断。

## 本次结论

- MIMIC PERform 独立受试者测试：**通过**
- P001～P043 正常/伪影短程回放：**通过**
- 是否可以进入实物短程回归：**可以**
- `RHYTHM_MODEL_CALIBRATED`：仍须保持 `false`，直到烧录后完成 2～3 组实物静止测试。

## 数据划分

按受试者划分训练、验证和测试集合，同一人的窗口不会跨集合，避免数据泄漏。

公开数据共提取 7306 个可用窗口；因峰值不足、长间隔或窗口末端心搏过期而丢弃 1024 个（12.3%）。

| 集合 | 受试者 | 窗口 |
|---|---:|---:|
| 训练 | 20 | 4486 |
| 验证 | 7 | 1438 |
| 独立测试 | 7 | 1382 |

## 独立测试结果（INT8 候选模型）

| 粒度 | 灵敏度 | 特异度 | 平衡准确率 | AUC |
|---|---:|---:|---:|---:|
| 固件连续3窗口告警/受试者 | 100.0% | 100.0% | 100.0% | 1.0 |
| 窗口概率中位数/受试者（辅助） | 100.0% | 66.7% | 83.3% | 0.6666666666666667 |
| 15秒窗口 | 79.2% | 99.4% | 89.3% | 0.9925097160878878 |

按固件连续三窗口规则，独立非房颤数据中的假告警率为 0.000 次/小时。

浮点模型与 INT8 模型分类一致率：99.6%。

## 本地 P001～P043 回放

- 找到文件：43 个
- 实际有固件推理点的文件：25 个
- 通过质量门控的推理窗口：144 个
- 原始 AF-like 窗口：12 个
- 连续 3 窗口形成的 `SUSPECTED_AF`：0 个

这些记录没有同步 ECG 房颤金标准，只能用于确认正常和伪影场景没有新增严重假报警。

## 固件编译验证（2026-09-03）

- PlatformIO 环境 `esp32-s3-cam`：**编译通过**。
- 候选模型常量：18 bytes。
- 完整固件 RAM：55308 / 327680 bytes（16.9%）。
- 完整固件 Flash：1012797 / 1966080 bytes（51.5%）。
- 实机推理耗时：尚待烧录后用 P044～P046 记录统计。

## 后续必须完成

1. 候选头文件已接入，PlatformIO 编译已通过；拿到实机后烧录。
2. 实物重新采 P044～P046 三组 45～60 秒正常静止 PPG，最终状态应为 `NORMAL`，且无新增严重假报警。
3. 用 `check_hardware_regression.py` 统计模型字节数和推理耗时平均值、P95、最大值。
4. 全部通过后，才把 `RHYTHM_MODEL_CALIBRATED` 改为 `true`。

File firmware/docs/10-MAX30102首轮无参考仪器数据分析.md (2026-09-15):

# MAX30102 首轮无参考仪器数据分析

## 1. 数据范围与结论边界

- 数据目录：`upper_computer/ppg_captures`；
- 试验编号：P001～P011，共 11 个场景；
- 总样本数：19389；
- 总记录时长：776.21 s（约 12 分 56 秒）；
- 本轮未使用标准心率/血氧仪，因此不计算 HR/SpO₂ 的 MAE、Bias 或 RMSE；
- 本轮结论只覆盖串口链路、手指检测、PPG 信号质量、趋势、运动抑制、节律状态机和端侧性能，不覆盖测量精度与医疗诊断能力。

## 2. 总体结果

| 检查项 | 结果 | 判断 |
|---|---:|---|
| 实际采样率 | 所有文件均为 25.0 Hz | 通过 |
| 序号丢帧 | 所有文件均为 0 | 通过 |
| 最大样本间隔 | 所有文件均为 50 ms | 通过 |
| FIFO 溢出 | 所有文件均为 0 | 通过 |
| ADC 削顶 | 所有场景均为 0 | 通过 |
| 无手指识别 | P001 手指率 0%、有效率 0%、状态 100% `NO_FINGER` | 初步通过 |
| 严重节律告警 | `SUSPECTED_AF` 为 0 次 | 本轮未误触发严重告警 |
| 模型校准标志 | 全部为 `model_calibrated=false` | 仍是未校准基线 |
| 捕获到的端侧推理 | 69 次 | 已超过 30 次性能记录要求 |
| 推理耗时 | 平均 65.2 μs，P95 96.6 μs，最大 112 μs | 通过 |
| 模型/分类器状态 | 30 B / 60 B | 已记录 |

传输链路和高频采集功能稳定，可以作为后续调试工具继续使用。

## 3. 各场景摘要

| 编号 | 场景 | 时长/s | 手指率 | 有效率 | 平均 SQI | 平均 HR | 平均 SpO₂ | 主要现象 |
|---|---|---:|---:|---:|---:|---:|---:|---|
| P001 | 无手指空载 | 17.62 | 0.0% | 0.0% | 0.000 | — | — | 全程 `NO_FINGER` |
| P002 | 稳定覆盖·静止 | 58.00 | 100% | 85.4% | 0.803 | 74.03 | 97.76 | 有效，但 HR 波动和少量异常 IBI 仍明显 |
| P003 | 重复放置/移开 | 50.35 | 69.9% | 10.4% | 0.263 | 71.98 | 97.64 | 检出 17 次手指状态跳变，超过“6 次放置/移开”通常对应的 12 次边沿 |
| P004 | 轻压 | 31.61 | 100% | 74.7% | 0.651 | 88.81 | 93.49 | 压力不足导致波形不稳，26.7% 接受 IBI 小于 500 ms |
| P005 | 正常按压 | 65.74 | 100% | 81.7% | 0.643 | 75.63 | 95.30 | IBI 最稳定，52 个 IBI 均在 520～960 ms |
| P006 | 重压 | 45.79 | 100% | 17.5% | 0.274 | 65.63 | 87.67 | 质量明显崩溃，说明接触压力影响很大 |
| P007 | 手指轻微移动 | 41.06 | 100% | 64.2% | 0.804 | 73.83 | 94.05 | 未进入 `MOTION_ARTIFACT`，但一直停在 `COLLECTING`，没有输出终态异常 |
| P008 | 拐杖轻微晃动 | 41.42 | 100% | 80.7% | 0.746 | 70.15 | 96.21 | `MOTION_ARTIFACT` 占 51.1%，IMU 抑制生效；恢复后出现一次低置信 `IRREGULAR` |
| P009 | 强环境光 | 49.39 | 100% | 91.9% | 0.866 | 76.94 | 97.59 | 本轮环境光条件下表现稳定 |
| P010 | 运动后恢复 | 211.84 | 100% | 89.3% | 0.892 | 69.74 | 97.48 | HR 从约 85 bpm 逐步降至 64～70 bpm，趋势跟踪有效 |
| P011 | 节律稳定窗口 | 163.39 | 98.8% | 79.6% | 0.858 | 82.20 | 98.01 | 开始后又移开过手指；40 s 后数据明显稳定，无 `IRREGULAR`/`SUSPECTED_AF` |

表中的 HR/SpO₂ 是设备自身输出的均值，不代表与真实值一致。

## 4. 关键分析

### 4.1 手指检测

P001 全程正确保持 `NO_FINGER`，说明空载阈值在本轮背景条件下没有误触发。P003 能够清楚地区分放置和移开，但记录中出现 17 次状态跳变。由于只有一个 `ACTION_START` 标记，没有每次实际放置/移开的人工时间标签，当前不能判断多出的边沿来自额外操作、接触抖动还是阈值抖动。

结论：空载检测初步通过；放指/移开响应时间和混淆统计尚未完成严格验收。

### 4.2 PPG 波形和压力影响

有手指场景的 RED/IR AC 相关系数约为 0.914～0.996，说明两路信号大体包含一致的脉搏成分。所有场景都没有 ADC 削顶，但“不削顶”并不等于“接触良好”。

压力影响非常显著：正常按压 P005 的 IBI 最整齐；轻压 P004 出现较多短 IBI；重压 P006 的有效率仅 17.5%，SQI 降至 0.274，SpO₂ 输出降至 87.67%。这组数据说明当前 SpO₂ 对接触压力不够鲁棒，也说明 SQI/valid 能在部分恶劣接触下拒绝输出，但拒绝还不完全。

### 4.3 HR 与 SpO₂

P010 运动后恢复记录提供了较好的趋势证据：有效输出开始后，10 秒分段 HR 从约 84～85 bpm 逐渐下降到约 64～70 bpm。该结果可以支持“能够跟踪心率变化趋势”，不能支持“心率精度达到某误差范围”。

SpO₂ 在 P002、P009、P010 的稳定段大多位于 97%～99%，但在轻压、重压和部分重新放置阶段可下降到明显不合理的区间。没有参考仪器时，不能判断稳定段是否准确，只能确认当前算法对压力和瞬态接触敏感。
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

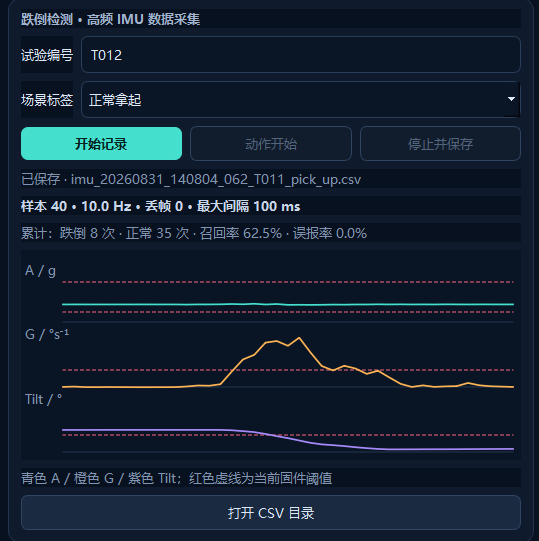
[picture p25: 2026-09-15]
media/screenshots/screenshot-2026-08-31 140823.png

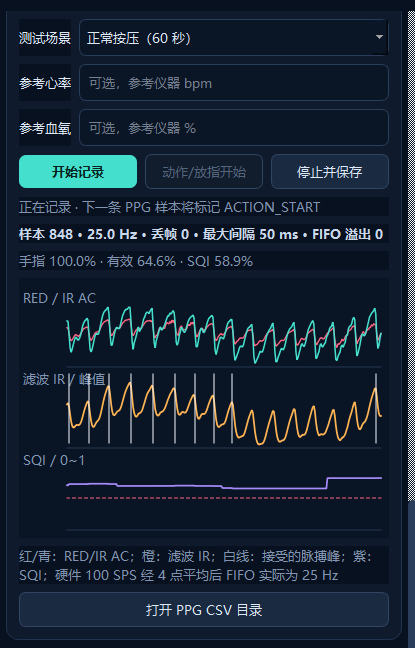
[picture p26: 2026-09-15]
media/screenshots/screenshot-2026-08-31 210006.png

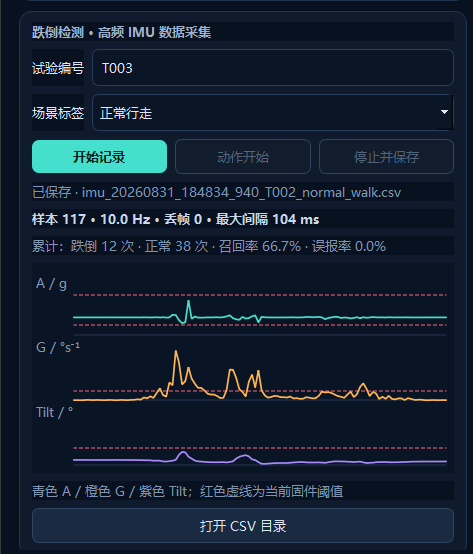
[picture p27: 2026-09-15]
media/screenshots/screenshot-2026-08-31 184856.png

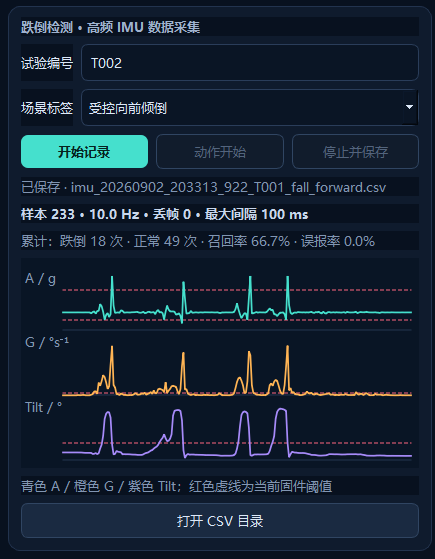
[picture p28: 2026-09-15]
media/screenshots/screenshot-2026-09-02 203343.png

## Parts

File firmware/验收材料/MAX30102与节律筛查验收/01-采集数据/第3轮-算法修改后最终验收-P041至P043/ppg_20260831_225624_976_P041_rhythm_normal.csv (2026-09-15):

pc_time | pc_monotonic_ms | trial_id | label | expected_state | reference_hr_bpm | reference_spo2_pct | action_marker | seq | t_ms | red | ir | red_dc | ir_dc | red_ac | ir_ac | filtered_ir | envelope | peak_candidate | beat_accepted | ibi_ms | finger | sqi | hr_bpm | spo2_pct | valid | fifo_overflow | rhythm_state | rhythm_valid | rhythm_confidence | model_calibrated | rhythm_ibi_mean_ms | rhythm_sdnn_ms | rhythm_rmssd_ms | rhythm_pnn50 | rhythm_beat_count | rhythm_inference_us | rhythm_inference_count | rhythm_model_bytes | rhythm_classifier_state_bytes | imu_accel_g | imu_gyro_dps
2026-08-31T22:56:25.254 | 128224500 | P041 | rhythm_normal | NORMAL |  |  |  | 1 | 244185 | 1269 | 782 | nan | nan | nan | nan | nan | nan | False | False | nan | False | 0.0 | nan | nan | False | 0 | NO_FINGER | 0 |  | 0 |  |  |  |  | 0 | 0 | 0 | 30 | 60 | 0.9992687326240124 | 0.17320508075688776
2026-08-31T22:56:25.406 | 128224656 | P041 | rhythm_normal | NORMAL |  |  |  | 2 | 244225 | 1272 | 777 | nan | nan | nan | nan | nan | nan | False | False | nan | False | 0.0 | nan | nan | False | 0 | NO_FINGER | 0 |  | 0 |  |  |  |  | 0 | 0 | 0 | 30 | 60 | 0.9992687326240124 | 0.17320508075688776
2026-08-31T22:56:25.422 | 128224671 | P041 | rhythm_normal | NORMAL |  |  |  | 3 | 244265 | 1269 | 775 | nan | nan | nan | nan | nan | nan | False | False | nan | False | 0.0 | nan | nan | False | 0 | NO_FINGER | 0 |  | 0 |  |  |  |  | 0 | 0 | 0 | 30 | 60 | 0.9992687326240124 | 0.17320508075688776
2026-08-31T22:56:25.434 | 128224687 | P041 | rhythm_normal | NORMAL |  |  |  | 4 | 244305 | 1268 | 781 | nan | nan | nan | nan | nan | nan | False | False | nan | False | 0.0 | nan | nan | False | 0 | NO_FINGER | 0 |  | 0 |  |  |  |  | 0 | 0 | 0 | 30 | 60 | 0.9992687326240124 | 0.17320508075688776
2026-08-31T22:56:25.444 | 128224687 | P041 | rhythm_normal | NORMAL |  |  |  | 5 | 244345 | 1270 | 773 | nan | nan | nan | nan | nan | nan | False | False | nan | False | 0.0 | nan | nan | False | 0 | NO_FINGER | 0 |  | 0 |  |  |  |  | 0 | 0 | 0 | 30 | 60 | 0.9992687326240124 | 0.17320508075688776
2026-08-31T22:56:25.455 | 128224703 | P041 | rhythm_normal | NORMAL |  |  |  | 6 | 244385 | 1274 | 791 | nan | nan | nan | nan | nan | nan | False | False | nan | False | 0.0 | nan | nan | False | 0 | NO_FINGER | 0 |  | 0 |  |  |  |  | 0 | 0 | 0 | 30 | 60 | 0.9992687326240124 | 0.17320508075688776
2026-08-31T22:56:25.608 | 128224859 | P041 | rhythm_normal | NORMAL |  |  |  | 7 | 244425 | 1278 | 789 | nan | nan | nan | nan | nan | nan | False | False | nan | False | 0.0 | nan | nan | False | 0 | NO_FINGER | 0 |  | 0 |  |  |  |  | 0 | 0 | 0 | 30 | 60 | 0.9992687326240124 | 0.17320508075688776
2026-08-31T22:56:25.619 | 128224875 | P041 | rhythm_normal | NORMAL |  |  |  | 8 | 244465 | 1287 | 791 | nan | nan | nan | nan | nan | nan | False | False | nan | False | 0.0 | nan | nan | False | 0 | NO_FINGER | 0 |  | 0 |  |  |  |  | 0 | 0 | 0 | 30 | 60 | 0.9992687326240124 | 0.17320508075688776
2026-08-31T22:56:25.628 | 128224875 | P041 | rhythm_normal | NORMAL |  |  |  | 9 | 244505 | 1308 | 788 | nan | nan | nan | nan | nan | nan | False | False | nan | False | 0.0 | nan | nan | False | 0 | NO_FINGER | 0 |  | 0 |  |  |  |  | 0 | 0 | 0 | 30 | 60 | 0.9992687326240124 | 0.17320508075688776
2026-08-31T22:56:25.635 | 128224890 | P041 | rhythm_normal | NORMAL |  |  |  | 10 | 244545 | 1306 | 799 | nan | nan | nan | nan | nan | nan | False | False | nan | False | 0.0 | nan | nan | False | 0 | NO_FINGER | 0 |  | 0 |  |  |  |  | 0 | 0 | 0 | 30 | 60 | 0.9992687326240124 | 0.17320508075688776
2026-08-31T22:56:25.660 | 128224906 | P041 | rhythm_normal | NORMAL |  |  |  | 11 | 244585 | 1298 | 777 | nan | nan | nan | nan | nan | nan | False | False | nan | False | 0.0 | nan | nan | False | 0 | NO_FINGER | 0 |  | 0 |  |  |  |  | 0 | 0 | 0 | 30 | 60 | 0.9992687326240124 | 0.17320508075688776
2026-08-31T22:56:25.816 | 128225062 | P041 | rhythm_normal | NORMAL |  |  |  | 12 | 244625 | 1310 | 792 | nan | nan | nan | nan | nan | nan | False | False | nan | False | 0.0 | nan | nan | False | 0 | NO_FINGER | 0 |  | 0 |  |  |  |  | 0 | 0 | 0 | 30 | 60 | 0.9992687326240124 | 0.17320508075688776
2026-08-31T22:56:25.828 | 128225078 | P041 | rhythm_normal | NORMAL |  |  |  | 13 | 244665 | 1318 | 798 | nan | nan | nan | nan | nan | nan | False | False | nan | False | 0.0 | nan | nan | False | 0 | NO_FINGER | 0 |  | 0 |  |  |  |  | 0 | 0 | 0 | 30 | 60 | 0.9992687326240124 | 0.17320508075688776
2026-08-31T22:56:25.837 | 128225093 | P041 | rhythm_normal | NORMAL |  |  |  | 14 | 244705 | 1308 | 782 | nan | nan | nan | nan | nan | nan | False | False | nan | False | 0.0 | nan | nan | False | 0 | NO_FINGER | 0 |  | 0 |  |  |  |  | 0 | 0 | 0 | 30 | 60 | 0.9992687326240124 | 0.17320508075688776
2026-08-31T22:56:25.845 | 128225093 | P041 | rhythm_normal | NORMAL |  |  |  | 15 | 244745 | 1319 | 791 | nan | nan | nan | nan | nan | nan | False | False | nan | False | 0.0 | nan | nan | False | 0 | NO_FINGER | 0 |  | 0 |  |  |  |  | 0 | 0 | 0 | 30 | 60 | 0.9992687326240124 | 0.17320508075688776
2026-08-31T22:56:25.855 | 128225109 | P041 | rhythm_normal | NORMAL |  |  |  | 16 | 244785 | 1331 | 790 | nan | nan | nan | nan | nan | nan | False | False | nan | False | 0.0 | nan | nan | False | 0 | NO_FINGER | 0 |  | 0 |  |  |  |  | 0 | 0 | 0 | 30 | 60 | 0.9992687326240124 | 0.17320508075688776
2026-08-31T22:56:26.011 | 128225265 | P041 | rhythm_normal | NORMAL |  |  |  | 17 | 244825 | 1333 | 796 | nan | nan | nan | nan | nan | nan | False | False | nan | False | 0.0 | nan | nan | False | 0 | NO_FINGER | 0 |  | 0 |  |  |  |  | 0 | 0 | 0 | 30 | 60 | 0.9992687326240124 | 0.17320508075688776
2026-08-31T22:56:26.020 | 128225265 | P041 | rhythm_normal | NORMAL |  |  |  | 18 | 244865 | 1339 | 799 | nan | nan | nan | nan | nan | nan | False | False | nan | False | 0.0 | nan | nan | False | 0 | NO_FINGER | 0 |  | 0 |  |  |  |  | 0 | 0 | 0 | 30 | 60 | 0.9992687326240124 | 0.17320508075688776
2026-08-31T22:56:26.026 | 128225281 | P041 | rhythm_normal | NORMAL |  |  |  | 19 | 244905 | 1319 | 797 | nan | nan | nan | nan | nan | nan | False | False | nan | False | 0.0 | nan | nan | False | 0 | NO_FINGER | 0 |  | 0 |  |  |  |  | 0 | 0 | 0 | 30 | 60 | 0.9992687326240124 | 0.17320508075688776
2026-08-31T22:56:26.032 | 128225281 | P041 | rhythm_normal | NORMAL |  |  |  | 20 | 244945 | 1311 | 789 | nan | nan | nan | nan | nan | nan | False | False | nan | False | 0.0 | nan | nan | False | 0 | NO_FINGER | 0 |  | 0 |  |  |  |  | 0 | 0 | 0 | 30 | 60 | 0.9992687326240124 | 0.17320508075688776
2026-08-31T22:56:26.056 | 128225312 | P041 | rhythm_normal | NORMAL |  |  |  | 21 | 244985 | 1315 | 794 | nan | nan | nan | nan | nan | nan | False | False | nan | False | 0.0 | nan | nan | False | 0 | NO_FINGER | 0 |  | 0 |  |  |  |  | 0 | 0 | 0 | 30 | 60 | 0.9992687326240124 | 0.17320508075688776
2026-08-31T22:56:26.215 | 128225468 | P041 | rhythm_normal | NORMAL |  |  |  | 22 | 245025 | 1312 | 787 | nan | nan | nan | nan | nan | nan | False | False | nan | False | 0.0 | nan | nan | False | 0 | NO_FINGER | 0 |  | 0 |  |  |  |  | 0 | 0 | 0 | 30 | 60 | 0.9992687326240124 | 0.17320508075688776
2026-08-31T22:56:26.229 | 128225484 | P041 | rhythm_normal | NORMAL |  |  |  | 23 | 245065 | 1312 | 792 | nan | nan | nan | nan | nan | nan | False | False | nan | False | 0.0 | nan | nan | False | 0 | NO_FINGER | 0 |  | 0 |  |  |  |  | 0 | 0 | 0 | 30 | 60 | 0.9992687326240124 | 0.17320508075688776
2026-08-31T22:56:26.238 | 128225484 | P041 | rhythm_normal | NORMAL |  |  |  | 24 | 245105 | 1320 | 794 | nan | nan | nan | nan | nan | nan | False | False | nan | False | 0.0 | nan | nan | False | 0 | NO_FINGER | 0 |  | 0 |  |  |  |  | 0 | 0 | 0 | 30 | 60 | 0.9992687326240124 | 0.17320508075688776
2026-08-31T22:56:26.248 | 128225500 | P041 | rhythm_normal | NORMAL |  |  |  | 25 | 245145 | 1318 | 789 | nan | nan | nan | nan | nan | nan | False | False | nan | False | 0.0 | nan | nan | False | 0 | NO_FINGER | 0 |  | 0 |  |  |  |  | 0 | 0 | 0 | 30 | 60 | 0.9992687326240124 | 0.17320508075688776
2026-08-31T22:56:26.261 | 128225515 | P041 | rhythm_normal | NORMAL |  |  |  | 26 | 245185 | 1323 | 793 | nan | nan | nan | nan | nan | nan | False | False | nan | False | 0.0 | nan | nan | False | 0 | NO_FINGER | 0 |  | 0 |  |  |  |  | 0 | 0 | 0 | 30 | 60 | 0.9992687326240124 | 0.17320508075688776
2026-08-31T22:56:26.411 | 128225656 | P041 | rhythm_normal | NORMAL |  |  |  | 27 | 245225 | 1326 | 801 | nan | nan | nan | nan | nan | nan | False | False | nan | False | 0.0 | nan | nan | False | 0 | NO_FINGER | 0 |  | 0 |  |  |  |  | 0 | 0 | 0 | 30 | 60 | 0.9992687326240124 | 0.17320508075688776
2026-08-31T22:56:26.425 | 128225671 | P041 | rhythm_normal | NORMAL |  |  |  | 28 | 245265 | 1309 | 786 | nan | nan | nan | nan | nan | nan | False | False | nan | False | 0.0 | nan | nan | False | 0 | NO_FINGER | 0 |  | 0 |  |  |  |  | 0 | 0 | 0 | 30 | 60 | 0.9992687326240124 | 0.17320508075688776
2026-08-31T22:56:26.440 | 128225687 | P041 | rhythm_normal | NORMAL |  |  |  | 29 | 245305 | 1307 | 795 | nan | nan | nan | nan | nan | nan | False | False | nan | False | 0.0 | nan | nan | False | 0 | NO_FINGER | 0 |  | 0 |  |  |  |  | 0 | 0 | 0 | 30 | 60 | 0.9992687326240124 | 0.17320508075688776
2026-08-31T22:56:26.449 | 128225703 | P041 | rhythm_normal | NORMAL |  |  |  | 30 | 245345 | 1310 | 785 | nan | nan | nan | nan | nan | nan | False | False | nan | False | 0.0 | nan | nan | False | 0 | NO_FINGER | 0 |  | 0 |  |  |  |  | 0 | 0 | 0 | 30 | 60 | 0.9992687326240124 | 0.17320508075688776
2026-08-31T22:56:26.462 | 128225718 | P041 | rhythm_normal | NORMAL |  |  |  | 31 | 245385 | 1313 | 795 | nan | nan | nan | nan | nan | nan | False | False | nan | False | 0.0 | nan | nan | False | 0 | NO_FINGER | 0 |  | 0 |  |  |  |  | 0 | 0 | 0 | 30 | 60 | 0.9992687326240124 | 0.17320508075688776
2026-08-31T22:56:26.613 | 128225859 | P041 | rhythm_normal | NORMAL |  |  |  | 32 | 245425 | 1309 | 795 | nan | nan | nan | nan | nan | nan | False | False | nan | False | 0.0 | nan | nan | False | 0 | NO_FINGER | 0 |  | 0 |  |  |  |  | 0 | 0 | 0 | 30 | 60 | 0.9992687326240124 | 0.17320508075688776
2026-08-31T22:56:26.625 | 128225875 | P041 | rhythm_normal | NORMAL |  |  |  | 33 | 245465 | 1305 | 790 | nan | nan | nan | nan | nan | nan | False | False | nan | False | 0.0 | nan | nan | False | 0 | NO_FINGER | 0 |  | 0 |  |  |  |  | 0 | 0 | 0 | 30 | 60 | 0.9992687326240124 | 0.17320508075688776
2026-08-31T22:56:26.633 | 128225890 | P041 | rhythm_normal | NORMAL |  |  |  | 34 | 245505 | 1309 | 794 | nan | nan | nan | nan | nan | nan | False | False | nan | False | 0.0 | nan | nan | False | 0 | NO_FINGER | 0 |  | 0 |  |  |  |  | 0 | 0 | 0 | 30 | 60 | 0.9992687326240124 | 0.17320508075688776
2026-08-31T22:56:26.643 | 128225890 | P041 | rhythm_normal | NORMAL |  |  |  | 35 | 245545 | 1305 | 789 | nan | nan | nan | nan | nan | nan | False | False | nan | False | 0.0 | nan | nan | False | 0 | NO_FINGER | 0 |  | 0 |  |  |  |  | 0 | 0 | 0 | 30 | 60 | 0.9992687326240124 | 0.17320508075688776
2026-08-31T22:56:26.665 | 128225921 | P041 | rhythm_normal | NORMAL |  |  |  | 36 | 245585 | 1305 | 787 | nan | nan | nan | nan | nan | nan | False | False | nan | False | 0.0 | nan | nan | False | 0 | NO_FINGER | 0 |  | 0 |  |  |  |  | 0 | 0 | 0 | 30 | 60 | 0.9992687326240124 | 0.17320508075688776
2026-08-31T22:56:26.809 | 128226062 | P041 | rhythm_normal | NORMAL |  |  |  | 37 | 245625 | 1301 | 792 | nan | nan | nan | nan | nan | nan | False | False | nan | False | 0.0 | nan | nan | False | 0 | NO_FINGER | 0 |  | 0 |  |  |  |  | 0 | 0 | 0 | 30 | 60 | 0.9992687326240124 | 0.17320508075688776
2026-08-31T22:56:26.822 | 128226078 | P041 | rhythm_normal | NORMAL |  |  |  | 38 | 245665 | 1309 | 800 | nan | nan | nan | nan | nan | nan | False | False | nan | False | 0.0 | nan | nan | False | 0 | NO_FINGER | 0 |  | 0 |  |  |  |  | 0 | 0 | 0 | 30 | 60 | 0.9992687326240124 | 0.17320508075688776
2026-08-31T22:56:26.832 | 128226078 | P041 | rhythm_normal | NORMAL |  |  |  | 39 | 245705 | 1314 | 795 | nan | nan | nan | nan | nan | nan | False | False | nan | False | 0.0 | nan | nan | False | 0 | NO_FINGER | 0 |  | 0 |  |  |  |  | 0 | 0 | 0 | 30 | 60 | 0.9992687326240124 | 0.17320508075688776
2026-08-31T22:56:26.852 | 128226109 | P041 | rhythm_normal | NORMAL |  |  |  | 40 | 245745 | 1313 | 803 | nan | nan | nan | nan | nan | nan | False | False | nan | False | 0.0 | nan | nan | False | 0 | NO_FINGER | 0 |  | 0 |  |  |  |  | 0 | 0 | 0 | 30 | 60 | 0.9992687326240124 | 0.17320508075688776
2026-08-31T22:56:26.861 | 128226109 | P041 | rhythm_normal | NORMAL |  |  |  | 41 | 245785 | 1319 | 791 | nan | nan | nan | nan | nan | nan | False | False | nan | False | 0.0 | nan | nan | False | 0 | NO_FINGER | 0 |  | 0 |  |  |  |  | 0 | 0 | 0 | 30 | 60 | 0.9992687326240124 | 0.17320508075688776
2026-08-31T22:56:27.003 | 128226250 | P041 | rhythm_normal | NORMAL |  |  |  | 42 | 245825 | 1320 | 797 | nan | nan | nan | nan | nan | nan | False | False | nan | False | 0.0 | nan | nan | False | 0 | NO_FINGER | 0 |  | 0 |  |  |  |  | 0 | 0 | 0 | 30 | 60 | 0.9992687326240124 | 0.17320508075688776
2026-08-31T22:56:27.015 | 128226265 | P041 | rhythm_normal | NORMAL |  |  |  | 43 | 245865 | 1317 | 798 | nan | nan | nan | nan | nan | nan | False | False | nan | False | 0.0 | nan | nan | False | 0 | NO_FINGER | 0 |  | 0 |  |  |  |  | 0 | 0 | 0 | 30 | 60 | 0.9992687326240124 | 0.17320508075688776
2026-08-31T22:56:27.027 | 128226281 | P041 | rhythm_normal | NORMAL |  |  |  | 44 | 245905 | 1316 | 802 | nan | nan | nan | nan | nan | nan | False | False | nan | False | 0.0 | nan | nan | False | 0 | NO_FINGER | 0 |  | 0 |  |  |  |  | 0 | 0 | 0 | 30 | 60 | 0.9992687326240124 | 0.17320508075688776
2026-08-31T22:56:27.037 | 128226281 | P041 | rhythm_normal | NORMAL |  |  |  | 45 | 245945 | 1319 | 796 | nan | nan | nan | nan | nan | nan | False | False | nan | False | 0.0 | nan | nan | False | 0 | NO_FINGER | 0 |  | 0 |  |  |  |  | 0 | 0 | 0 | 30 | 60 | 0.9992687326240124 | 0.17320508075688776
2026-08-31T22:56:27.059 | 128226312 | P041 | rhythm_normal | NORMAL |  |  |  | 46 | 245985 | 1313 | 797 | nan | nan | nan | nan | nan | nan | False | False | nan | False | 0.0 | nan | nan | False | 0 | NO_FINGER | 0 |  | 0 |  |  |  |  | 0 | 0 | 0 | 30 | 60 | 0.9992687326240124 | 0.17320508075688776
2026-08-31T22:56:27.207 | 128226453 | P041 | rhythm_normal | NORMAL |  |  |  | 47 | 246025 | 1321 | 792 | nan | nan | nan | nan | nan | nan | False | False | nan | False | 0.0 | nan | nan | False | 0 | NO_FINGER | 0 |  | 0 |  |  |  |  | 0 | 0 | 0 | 30 | 60 | 0.9992687326240124 | 0.17320508075688776
2026-08-31T22:56:27.219 | 128226468 | P041 | rhythm_normal | NORMAL |  |  |  | 48 | 246065 | 1330 | 796 | nan | nan | nan | nan | nan | nan | False | False | nan | False | 0.0 | nan | nan | False | 0 | NO_FINGER | 0 |  | 0 |  |  |  |  | 0 | 0 | 0 | 30 | 60 | 0.9992687326240124 | 0.17320508075688776
2026-08-31T22:56:27.227 | 128226484 | P041 | rhythm_normal | NORMAL |  |  |  | 49 | 246105 | 1338 | 798 | nan | nan | nan | nan | nan | nan | False | False | nan | False | 0.0 | nan | nan | False | 0 | NO_FINGER | 0 |  | 0 |  |  |  |  | 0 | 0 | 0 | 30 | 60 | 0.9992687326240124 | 0.17320508075688776
2026-08-31T22:56:27.236 | 128226484 | P041 | rhythm_normal | NORMAL |  |  |  | 50 | 246145 | 1341 | 797 | nan | nan | nan | nan | nan | nan | False | False | nan | False | 0.0 | nan | nan | False | 0 | NO_FINGER | 0 |  | 0 |  |  |  |  | 0 | 0 | 0 | 30 | 60 | 0.9992687326240124 | 0.17320508075688776
2026-08-31T22:56:27.254 | 128226500 | P041 | rhythm_normal | NORMAL |  |  |  | 51 | 246185 | 1356 | 802 | nan | nan | nan | nan | nan | nan | False | False | nan | False | 0.0 | nan | nan | False | 0 | NO_FINGER | 0 |  | 0 |  |  |  |  | 0 | 0 | 0 | 30 | 60 | 0.9992687326240124 | 0.17320508075688776
2026-08-31T22:56:27.405 | 128226656 | P041 | rhythm_normal | NORMAL |  |  |  | 52 | 246225 | 1358 | 802 | nan | nan | nan | nan | nan | nan | False | False | nan | False | 0.0 | nan | nan | False | 0 | NO_FINGER | 0 |  | 0 |  |  |  |  | 0 | 0 | 0 | 30 | 60 | 0.9992687326240124 | 0.17320508075688776
2026-08-31T22:56:27.416 | 128226671 | P041 | rhythm_normal | NORMAL |  |  |  | 53 | 246265 | 1359 | 799 | nan | nan | nan | nan | nan | nan | False | False | nan | False | 0.0 | nan | nan | False | 0 | NO_FINGER | 0 |  | 0 |  |  |  |  | 0 | 0 | 0 | 30 | 60 | 0.9992687326240124 | 0.17320508075688776
2026-08-31T22:56:27.427 | 128226671 | P041 | rhythm_normal | NORMAL |  |  |  | 54 | 246305 | 1350 | 806 | nan | nan | nan | nan | nan | nan | False | False | nan | False | 0.0 | nan | nan | False | 0 | NO_FINGER | 0 |  | 0 |  |  |  |  | 0 | 0 | 0 | 30 | 60 | 0.9992687326240124 | 0.17320508075688776
2026-08-31T22:56:27.432 | 128226687 | P041 | rhythm_normal | NORMAL |  |  |  | 55 | 246345 | 1357 | 797 | nan | nan | nan | nan | nan | nan | False | False | nan | False | 0.0 | nan | nan | False | 0 | NO_FINGER | 0 |  | 0 |  |  |  |  | 0 | 0 | 0 | 30 | 60 | 0.9992687326240124 | 0.17320508075688776
2026-08-31T22:56:27.456 | 128226703 | P041 | rhythm_normal | NORMAL |  |  |  | 56 | 246385 | 1365 | 799 | nan | nan | nan | nan | nan | nan | False | False | nan | False | 0.0 | nan | nan | False | 0 | NO_FINGER | 0 |  | 0 |  |  |  |  | 0 | 0 | 0 | 30 | 60 | 0.9992687326240124 | 0.17320508075688776
2026-08-31T22:56:27.608 | 128226859 | P041 | rhythm_normal | NORMAL |  |  |  | 57 | 246425 | 1352 | 800 | nan | nan | nan | nan | nan | nan | False | False | nan | False | 0.0 | nan | nan | False | 0 | NO_FINGER | 0 |  | 0 |  |  |  |  | 0 | 0 | 0 | 30 | 60 | 0.9992687326240124 | 0.17320508075688776
2026-08-31T22:56:27.629 | 128226875 | P041 | rhythm_normal | NORMAL |  |  |  | 58 | 246465 | 1338 | 794 | nan | nan | nan | nan | nan | nan | False | False | nan | False | 0.0 | nan | nan | False | 0 | NO_FINGER | 0 |  | 0 |  |  |  |  | 0 | 0 | 0 | 30 | 60 | 0.9992687326240124 | 0.17320508075688776
2026-08-31T22:56:27.639 | 128226890 | P041 | rhythm_normal | NORMAL |  |  |  | 59 | 246505 | 1329 | 798 | nan | nan | nan | nan | nan | nan | False | False | nan | False | 0.0 | nan | nan | False | 0 | NO_FINGER | 0 |  | 0 |  |  |  |  | 0 | 0 | 0 | 30 | 60 | 0.9992687326240124 | 0.17320508075688776
2026-08-31T22:56:27.647 | 128226906 | P041 | rhythm_normal | NORMAL |  |  |  | 60 | 246545 | 1327 | 797 | nan | nan | nan | nan | nan | nan | False | False | nan | False | 0.0 | nan | nan | False | 0 | NO_FINGER | 0 |  | 0 |  |  |  |  | 0 | 0 | 0 | 30 | 60 | 0.9992687326240124 | 0.17320508075688776
2026-08-31T22:56:27.656 | 128226906 | P041 | rhythm_normal | NORMAL |  |  |  | 61 | 246585 | 1317 | 794 | nan | nan | nan | nan | nan | nan | False | False | nan | False | 0.0 | nan | nan | False | 0 | NO_FINGER | 0 |  | 0 |  |  |  |  | 0 | 0 | 0 | 30 | 60 | 0.9992687326240124 | 0.17320508075688776
2026-08-31T22:56:27.798 | 128227046 | P041 | rhythm_normal | NORMAL |  |  |  | 62 | 246625 | 1329 | 797 | nan | nan | nan | nan | nan | nan | False | False | nan | False | 0.0 | nan | nan | False | 0 | NO_FINGER | 0 |  | 0 |  |  |  |  | 0 | 0 | 0 | 30 | 60 | 0.9992687326240124 | 0.17320508075688776
2026-08-31T22:56:27.807 | 128227062 | P041 | rhythm_normal | NORMAL |  |  |  | 63 | 246665 | 1354 | 794 | nan | nan | nan | nan | nan | nan | False | False | nan | False | 0.0 | nan | nan | False | 0 | NO_FINGER | 0 |  | 0 |  |  |  |  | 0 | 0 | 0 | 30 | 60 | 0.9992687326240124 | 0.17320508075688776
2026-08-31T22:56:27.816 | 128227062 | P041 | rhythm_normal | NORMAL |  |  |  | 64 | 246705 | 1349 | 799 | nan | nan | nan | nan | nan | nan | False | False | nan | False | 0.0 | nan | nan | False | 0 | NO_FINGER | 0 |  | 0 |  |  |  |  | 0 | 0 | 0 | 30 | 60 | 0.9992687326240124 | 0.17320508075688776
2026-08-31T22:56:27.825 | 128227078 | P041 | rhythm_normal | NORMAL |  |  |  | 65 | 246745 | 1350 | 798 | nan | nan | nan | nan | nan | nan | False | False | nan | False | 0.0 | nan | nan | False | 0 | NO_FINGER | 0 |  | 0 |  |  |  |  | 0 | 0 | 0 | 30 | 60 | 0.9992687326240124 | 0.17320508075688776
2026-08-31T22:56:27.861 | 128227109 | P041 | rhythm_normal | NORMAL |  |  |  | 66 | 246785 | 1345 | 805 | nan | nan | nan | nan | nan | nan | False | False | nan | False | 0.0 | nan | nan | False | 0 | NO_FINGER | 0 |  | 0 |  |  |  |  | 0 | 0 | 0 | 30 | 60 | 0.9992687326240124 | 0.17320508075688776
2026-08-31T22:56:28.002 | 128227250 | P041 | rhythm_normal | NORMAL |  |  |  | 67 | 246825 | 1349 | 796 | nan | nan | nan | nan | nan | nan | False | False | nan | False | 0.0 | nan | nan | False | 0 | NO_FINGER | 0 |  | 0 |  |  |  |  | 0 | 0 | 0 | 30 | 60 | 0.9992687326240124 | 0.17320508075688776
2026-08-31T22:56:28.014 | 128227265 | P041 | rhythm_normal | NORMAL |  |  |  | 68 | 246865 | 1336 | 792 | nan | nan | nan | nan | nan | nan | False | False | nan | False | 0.0 | nan | nan | False | 0 | NO_FINGER | 0 |  | 0 |  |  |  |  | 0 | 0 | 0 | 30 | 60 | 0.9992687326240124 | 0.17320508075688776
2026-08-31T22:56:28.022 | 128227265 | P041 | rhythm_normal | NORMAL |  |  |  | 69 | 246905 | 1344 | 799 | nan | nan | nan | nan | nan | nan | False | False | nan | False | 0.0 | nan | nan | False | 0 | NO_FINGER | 0 |  | 0 |  |  |  |  | 0 | 0 | 0 | 30 | 60 | 0.9992687326240124 | 0.17320508075688776
2026-08-31T22:56:28.030 | 128227281 | P041 | rhythm_normal | NORMAL |  |  |  | 70 | 246945 | 1340 | 795 | nan | nan | nan | nan | nan | nan | False | False | nan | False | 0.0 | nan | nan | False | 0 | NO_FINGER | 0 |  | 0 |  |  |  |  | 0 | 0 | 0 | 30 | 60 | 0.9992687326240124 | 0.17320508075688776
2026-08-31T22:56:28.056 | 128227312 | P041 | rhythm_normal | NORMAL |  |  |  | 71 | 246985 | 1338 | 805 | nan | nan | nan | nan | nan | nan | False | False | nan | False | 0.0 | nan | nan | False | 0 | NO_FINGER | 0 |  | 0 |  |  |  |  | 0 | 0 | 0 | 30 | 60 | 0.9992687326240124 | 0.17320508075688776
2026-08-31T22:56:28.207 | 128227453 | P041 | rhythm_normal | NORMAL |  |  |  | 72 | 247025 | 1326 | 801 | nan | nan | nan | nan | nan | nan | False | False | nan | False | 0.0 | nan | nan | False | 0 | NO_FINGER | 0 |  | 0 |  |  |  |  | 0 | 0 | 0 | 30 | 60 | 0.9992687326240124 | 0.17320508075688776
2026-08-31T22:56:28.221 | 128227468 | P041 | rhythm_normal | NORMAL |  |  |  | 73 | 247065 | 1334 | 796 | nan | nan | nan | nan | nan | nan | False | False | nan | False | 0.0 | nan | nan | False | 0 | NO_FINGER | 0 |  | 0 |  |  |  |  | 0 | 0 | 0 | 30 | 60 | 0.9992687326240124 | 0.17320508075688776
2026-08-31T22:56:28.232 | 128227484 | P041 | rhythm_normal | NORMAL |  |  |  | 74 | 247105 | 1338 | 796 | nan | nan | nan | nan | nan | nan | False | False | nan | False | 0.0 | nan | nan | False | 0 | NO_FINGER | 0 |  | 0 |  |  |  |  | 0 | 0 | 0 | 30 | 60 | 0.9992687326240124 | 0.17320508075688776
2026-08-31T22:56:28.239 | 128227484 | P041 | rhythm_normal | NORMAL |  |  |  | 75 | 247145 | 1336 | 797 | nan | nan | nan | nan | nan | nan | False | False | nan | False | 0.0 | nan | nan | False | 0 | NO_FINGER | 0 |  | 0 |  |  |  |  | 0 | 0 | 0 | 30 | 60 | 0.9992687326240124 | 0.17320508075688776
2026-08-31T22:56:28.259 | 128227515 | P041 | rhythm_normal | NORMAL |  |  |  | 76 | 247185 | 1338 | 801 | nan | nan | nan | nan | nan | nan | False | False | nan | False | 0.0 | nan | nan | False | 0 | NO_FINGER | 0 |  | 0 |  |  |  |  | 0 | 0 | 0 | 30 | 60 | 0.9992687326240124 | 0.17320508075688776
2026-08-31T22:56:28.399 | 128227656 | P041 | rhythm_normal | NORMAL |  |  |  | 77 | 247225 | 1335 | 793 | nan | nan | nan | nan | nan | nan | False | False | nan | False | 0.0 | nan | nan | False | 0 | NO_FINGER | 0 |  | 0 |  |  |  |  | 0 | 0 | 0 | 30 | 60 | 0.9992687326240124 | 0.17320508075688776
2026-08-31T22:56:28.416 | 128227671 | P041 | rhythm_normal | NORMAL |  |  |  | 78 | 247265 | 1335 | 802 | nan | nan | nan | nan | nan | nan | False | False | nan | False | 0.0 | nan | nan | False | 0 | NO_FINGER | 0 |  | 0 |  |  |  |  | 0 | 0 | 0 | 30 | 60 | 0.9992687326240124 | 0.17320508075688776
2026-08-31T22:56:28.427 | 128227671 | P041 | rhythm_normal | NORMAL |  |  |  | 79 | 247305 | 1333 | 794 | nan | nan | nan | nan | nan | nan | False | False | nan | False | 0.0 | nan | nan | False | 0 | NO_FINGER | 0 |  | 0 |  |  |  |  | 0 | 0 | 0 | 30 | 60 | 0.9992687326240124 | 0.17320508075688776
2026-08-31T22:56:28.437 | 128227687 | P041 | rhythm_normal | NORMAL |  |  |  | 80 | 247345 | 1346 | 796 | nan | nan | nan | nan | nan | nan | False | False | nan | False | 0.0 | nan | nan | False | 0 | NO_FINGER | 0 |  | 0 |  |  |  |  | 0 | 0 | 0 | 30 | 60 | 0.9992687326240124 | 0.17320508075688776
2026-08-31T22:56:28.454 | 128227703 | P041 | rhythm_normal | NORMAL |  |  |  | 81 | 247385 | 1341 | 798 | nan | nan | nan | nan | nan | nan | False | False | nan | False | 0.0 | nan | nan | False | 0 | NO_FINGER | 0 |  | 0 |  |  |  |  | 0 | 0 | 0 | 30 | 60 | 0.9992687326240124 | 0.17320508075688776
2026-08-31T22:56:28.609 | 128227859 | P041 | rhythm_normal | NORMAL |  |  |  | 82 | 247425 | 1338 | 802 | nan | nan | nan | nan | nan | nan | False | False | nan | False | 0.0 | nan | nan | False | 0 | NO_FINGER | 0 |  | 0 |  |  |  |  | 0 | 0 | 0 | 30 | 60 | 0.9996974542330294 | 0.17320508075688776
2026-08-31T22:56:28.618 | 128227875 | P041 | rhythm_normal | NORMAL |  |  |  | 83 | 247465 | 1341 | 799 | nan | nan | nan | nan | nan | nan | False | False | nan | False | 0.0 | nan | nan | False | 0 | NO_FINGER | 0 |  | 0 |  |  |  |  | 0 | 0 | 0 | 30 | 60 | 0.9996974542330294 | 0.17320508075688776
2026-08-31T22:56:28.633 | 128227890 | P041 | rhythm_normal | NORMAL |  |  |  | 84 | 247505 | 1329 | 798 | nan | nan | nan | nan | nan | nan | False | False | nan | False | 0.0 | nan | nan | False | 0 | NO_FINGER | 0 |  | 0 |  |  |  |  | 0 | 0 | 0 | 30 | 60 | 0.9996974542330294 | 0.17320508075688776
2026-08-31T22:56:28.647 | 128227890 | P041 | rhythm_normal | NORMAL |  |  |  | 85 | 247545 | 1330 | 792 | nan | nan | nan | nan | nan | nan | False | False | nan | False | 0.0 | nan | nan | False | 0 | NO_FINGER | 0 |  | 0 |  |  |  |  | 0 | 0 | 0 | 30 | 60 | 0.9996974542330294 | 0.17320508075688776
2026-08-31T22:56:28.663 | 128227921 | P041 | rhythm_normal | NORMAL |  |  |  | 86 | 247585 | 1338 | 804 | nan | nan | nan | nan | nan | nan | False | False | nan | False | 0.0 | nan | nan | False | 0 | NO_FINGER | 0 |  | 0 |  |  |  |  | 0 | 0 | 0 | 30 | 60 | 0.9996974542330294 | 0.17320508075688776
2026-08-31T22:56:28.817 | 128228062 | P041 | rhythm_normal | NORMAL |  |  |  | 87 | 247625 | 1345 | 803 | nan | nan | nan | nan | nan | nan | False | False | nan | False | 0.0 | nan | nan | False | 0 | NO_FINGER | 0 |  | 0 |  |  |  |  | 0 | 0 | 0 | 30 | 60 | 0.9992687326240124 | 0.17320508075688776
2026-08-31T22:56:28.824 | 128228078 | P041 | rhythm_normal | NORMAL |  |  |  | 88 | 247665 | 1342 | 794 | nan | nan | nan | nan | nan | nan | False | False | nan | False | 0.0 | nan | nan | False | 0 | NO_FINGER | 0 |  | 0 |  |  |  |  | 0 | 0 | 0 | 30 | 60 | 0.9992687326240124 | 0.17320508075688776
2026-08-31T22:56:28.835 | 128228078 | P041 | rhythm_normal | NORMAL |  |  |  | 89 | 247705 | 1335 | 799 | nan | nan | nan | nan | nan | nan | False | False | nan | False | 0.0 | nan | nan | False | 0 | NO_FINGER | 0 |  | 0 |  |  |  |  | 0 | 0 | 0 | 30 | 60 | 0.9992687326240124 | 0.17320508075688776
2026-08-31T22:56:28.855 | 128228109 | P041 | rhythm_normal | NORMAL |  |  |  | 90 | 247745 | 1340 | 798 | nan | nan | nan | nan | nan | nan | False | False | nan | False | 0.0 | nan | nan | False | 0 | NO_FINGER | 0 |  | 0 |  |  |  |  | 0 | 0 | 0 | 30 | 60 | 0.9992687326240124 | 0.17320508075688776
2026-08-31T22:56:28.869 | 128228125 | P041 | rhythm_normal | NORMAL |  |  |  | 91 | 247785 | 1335 | 796 | nan | nan | nan | nan | nan | nan | False | False | nan | False | 0.0 | nan | nan | False | 0 | NO_FINGER | 0 |  | 0 |  |  |  |  | 0 | 0 | 0 | 30 | 60 | 0.9992687326240124 | 0.17320508075688776
2026-08-31T22:56:29.017 | 128228265 | P041 | rhythm_normal | NORMAL |  |  |  | 92 | 247825 | 1348 | 798 | nan | nan | nan | nan | nan | nan | False | False | nan | False | 0.0 | nan | nan | False | 0 | NO_FINGER | 0 |  | 0 |  |  |  |  | 0 | 0 | 0 | 30 | 60 | 0.9992687326240124 | 0.17320508075688776
2026-08-31T22:56:29.034 | 128228281 | P041 | rhythm_normal | NORMAL |  |  |  | 93 | 247865 | 1341 | 798 | nan | nan | nan | nan | nan | nan | False | False | nan | False | 0.0 | nan | nan | False | 0 | NO_FINGER | 0 |  | 0 |  |  |  |  | 0 | 0 | 0 | 30 | 60 | 0.9992687326240124 | 0.17320508075688776
2026-08-31T22:56:29.046 | 128228296 | P041 | rhythm_normal | NORMAL |  |  |  | 94 | 247905 | 1364 | 812 | nan | nan | nan | nan | nan | nan | False | False | nan | False | 0.0 | nan | nan | False | 0 | NO_FINGER | 0 |  | 0 |  |  |  |  | 0 | 0 | 0 | 30 | 60 | 0.9992687326240124 | 0.17320508075688776
2026-08-31T22:56:29.056 | 128228312 | P041 | rhythm_normal | NORMAL |  |  |  | 95 | 247945 | 1369 | 804 | nan | nan | nan | nan | nan | nan | False | False | nan | False | 0.0 | nan | nan | False | 0 | NO_FINGER | 0 |  | 0 |  |  |  |  | 0 | 0 | 0 | 30 | 60 | 0.9992687326240124 | 0.17320508075688776
2026-08-31T22:56:29.062 | 128228312 | P041 | rhythm_normal | NORMAL |  |  |  | 96 | 247985 | 1367 | 799 | nan | nan | nan | nan | nan | nan | False | False | nan | False | 0.0 | nan | nan | False | 0 | NO_FINGER | 0 |  | 0 |  |  |  |  | 0 | 0 | 0 | 30 | 60 | 0.9992687326240124 | 0.17320508075688776
2026-08-31T22:56:29.222 | 128228468 | P041 | rhythm_normal | NORMAL |  |  |  | 97 | 248025 | 1353 | 798 | nan | nan | nan | nan | nan | nan | False | False | nan | False | 0.0 | nan | nan | False | 0 | NO_FINGER | 0 |  | 0 |  |  |  |  | 0 | 0 | 0 | 30 | 60 | 0.9992687326240124 | 0.17320508075688776
2026-08-31T22:56:29.246 | 128228500 | P041 | rhythm_normal | NORMAL |  |  |  | 98 | 248065 | 1362 | 800 | nan | nan | nan | nan | nan | nan | False | False | nan | False | 0.0 | nan | nan | False | 0 | NO_FINGER | 0 |  | 0 |  |  |  |  | 0 | 0 | 0 | 30 | 60 | 0.9992687326240124 | 0.17320508075688776
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

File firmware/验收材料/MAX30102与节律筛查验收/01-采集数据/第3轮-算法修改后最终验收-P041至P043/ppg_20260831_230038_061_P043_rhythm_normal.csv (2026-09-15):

pc_time | pc_monotonic_ms | trial_id | label | expected_state | reference_hr_bpm | reference_spo2_pct | action_marker | seq | t_ms | red | ir | red_dc | ir_dc | red_ac | ir_ac | filtered_ir | envelope | peak_candidate | beat_accepted | ibi_ms | finger | sqi | hr_bpm | spo2_pct | valid | fifo_overflow | rhythm_state | rhythm_valid | rhythm_confidence | model_calibrated | rhythm_ibi_mean_ms | rhythm_sdnn_ms | rhythm_rmssd_ms | rhythm_pnn50 | rhythm_beat_count | rhythm_inference_us | rhythm_inference_count | rhythm_model_bytes | rhythm_classifier_state_bytes | imu_accel_g | imu_gyro_dps
2026-08-31T23:00:38.292 | 128477546 | P043 | rhythm_normal | NORMAL |  |  |  | 1 | 497235 | 26550 | 19287 | nan | nan | nan | nan | nan | nan | False | False | nan | False | 0.0 | nan | nan | False | 0 | NO_FINGER | 0 |  | 0 |  |  |  |  | 0 | 56 | 28 | 30 | 60 | 0.999310262130836 | 0.24494897427831783
2026-08-31T23:00:38.439 | 128477687 | P043 | rhythm_normal | NORMAL |  |  |  | 2 | 497275 | 24947 | 17781 | nan | nan | nan | nan | nan | nan | False | False | nan | False | 0.0 | nan | nan | False | 0 | NO_FINGER | 0 |  | 0 |  |  |  |  | 0 | 56 | 28 | 30 | 60 | 0.999529889498058 | 0.24494897427831783
2026-08-31T23:00:38.446 | 128477703 | P043 | rhythm_normal | NORMAL |  |  |  | 3 | 497315 | 21314 | 15153 | nan | nan | nan | nan | nan | nan | False | False | nan | False | 0.0 | nan | nan | False | 0 | NO_FINGER | 0 |  | 0 |  |  |  |  | 0 | 56 | 28 | 30 | 60 | 0.999529889498058 | 0.24494897427831783
2026-08-31T23:00:38.455 | 128477703 | P043 | rhythm_normal | NORMAL |  |  |  | 4 | 497355 | 18125 | 13112 | nan | nan | nan | nan | nan | nan | False | False | nan | False | 0.0 | nan | nan | False | 0 | NO_FINGER | 0 |  | 0 |  |  |  |  | 0 | 56 | 28 | 30 | 60 | 0.999529889498058 | 0.24494897427831783
2026-08-31T23:00:38.459 | 128477703 | P043 | rhythm_normal | NORMAL |  |  |  | 5 | 497395 | 15954 | 11664 | nan | nan | nan | nan | nan | nan | False | False | nan | False | 0.0 | nan | nan | False | 0 | NO_FINGER | 0 |  | 0 |  |  |  |  | 0 | 56 | 28 | 30 | 60 | 0.999529889498058 | 0.24494897427831783
2026-08-31T23:00:38.494 | 128477750 | P043 | rhythm_normal | NORMAL |  |  |  | 6 | 497435 | 13594 | 9943 | nan | nan | nan | nan | nan | nan | False | False | nan | False | 0.0 | nan | nan | False | 0 | NO_FINGER | 0 |  | 0 |  |  |  |  | 0 | 56 | 28 | 30 | 60 | 0.999529889498058 | 0.24494897427831783
2026-08-31T23:00:38.636 | 128477890 | P043 | rhythm_normal | NORMAL |  |  |  | 7 | 497475 | 10704 | 7791 | nan | nan | nan | nan | nan | nan | False | False | nan | False | 0.0 | nan | nan | False | 0 | NO_FINGER | 0 |  | 0 |  |  |  |  | 0 | 56 | 28 | 30 | 60 | 1.0001889821428749 | 0.17320508075688776
2026-08-31T23:00:38.645 | 128477890 | P043 | rhythm_normal | NORMAL |  |  |  | 8 | 497515 | 8310 | 6119 | nan | nan | nan | nan | nan | nan | False | False | nan | False | 0.0 | nan | nan | False | 0 | NO_FINGER | 0 |  | 0 |  |  |  |  | 0 | 56 | 28 | 30 | 60 | 1.0001889821428749 | 0.17320508075688776
2026-08-31T23:00:38.652 | 128477906 | P043 | rhythm_normal | NORMAL |  |  |  | 9 | 497555 | 6377 | 4767 | nan | nan | nan | nan | nan | nan | False | False | nan | False | 0.0 | nan | nan | False | 0 | NO_FINGER | 0 |  | 0 |  |  |  |  | 0 | 56 | 28 | 30 | 60 | 1.0001889821428749 | 0.17320508075688776
2026-08-31T23:00:38.657 | 128477906 | P043 | rhythm_normal | NORMAL |  |  |  | 10 | 497595 | 4962 | 3817 | nan | nan | nan | nan | nan | nan | False | False | nan | False | 0.0 | nan | nan | False | 0 | NO_FINGER | 0 |  | 0 |  |  |  |  | 0 | 56 | 28 | 30 | 60 | 1.0001889821428749 | 0.17320508075688776
2026-08-31T23:00:38.693 | 128477937 | P043 | rhythm_normal | NORMAL |  |  |  | 11 | 497635 | 4120 | 3252 | nan | nan | nan | nan | nan | nan | False | False | nan | False | 0.0 | nan | nan | False | 0 | NO_FINGER | 0 |  | 0 |  |  |  |  | 0 | 56 | 28 | 30 | 60 | 1.0001889821428749 | 0.17320508075688776
2026-08-31T23:00:38.843 | 128478093 | P043 | rhythm_normal | NORMAL |  |  |  | 12 | 497675 | 3541 | 2831 | nan | nan | nan | nan | nan | nan | False | False | nan | False | 0.0 | nan | nan | False | 0 | NO_FINGER | 0 |  | 0 |  |  |  |  | 0 | 56 | 28 | 30 | 60 | 0.999310262130836 | 0.24494897427831783
2026-08-31T23:00:38.855 | 128478109 | P043 | rhythm_normal | NORMAL |  |  |  | 13 | 497715 | 3193 | 2567 | nan | nan | nan | nan | nan | nan | False | False | nan | False | 0.0 | nan | nan | False | 0 | NO_FINGER | 0 |  | 0 |  |  |  |  | 0 | 56 | 28 | 30 | 60 | 0.999310262130836 | 0.24494897427831783
2026-08-31T23:00:38.863 | 128478109 | P043 | rhythm_normal | NORMAL |  |  |  | 14 | 497755 | 3114 | 2505 | nan | nan | nan | nan | nan | nan | False | False | nan | False | 0.0 | nan | nan | False | 0 | NO_FINGER | 0 |  | 0 |  |  |  |  | 0 | 56 | 28 | 30 | 60 | 0.999310262130836 | 0.24494897427831783
2026-08-31T23:00:38.868 | 128478125 | P043 | rhythm_normal | NORMAL |  |  |  | 15 | 497795 | 3058 | 2475 | nan | nan | nan | nan | nan | nan | False | False | nan | False | 0.0 | nan | nan | False | 0 | NO_FINGER | 0 |  | 0 |  |  |  |  | 0 | 56 | 28 | 30 | 60 | 0.999310262130836 | 0.24494897427831783
2026-08-31T23:00:38.895 | 128478140 | P043 | rhythm_normal | NORMAL |  |  |  | 16 | 497835 | 2969 | 2426 | nan | nan | nan | nan | nan | nan | False | False | nan | False | 0.0 | nan | nan | False | 0 | NO_FINGER | 0 |  | 0 |  |  |  |  | 0 | 56 | 28 | 30 | 60 | 0.999310262130836 | 0.24494897427831783
2026-08-31T23:00:39.041 | 128478296 | P043 | rhythm_normal | NORMAL |  |  |  | 17 | 497875 | 2839 | 2319 | nan | nan | nan | nan | nan | nan | False | False | nan | False | 0.0 | nan | nan | False | 0 | NO_FINGER | 0 |  | 0 |  |  |  |  | 0 | 56 | 28 | 30 | 60 | 0.999310262130836 | 0.30000000000000004
2026-08-31T23:00:39.052 | 128478296 | P043 | rhythm_normal | NORMAL |  |  |  | 18 | 497915 | 2797 | 2277 | nan | nan | nan | nan | nan | nan | False | False | nan | False | 0.0 | nan | nan | False | 0 | NO_FINGER | 0 |  | 0 |  |  |  |  | 0 | 56 | 28 | 30 | 60 | 0.999310262130836 | 0.30000000000000004
2026-08-31T23:00:39.056 | 128478312 | P043 | rhythm_normal | NORMAL |  |  |  | 19 | 497955 | 2785 | 2255 | nan | nan | nan | nan | nan | nan | False | False | nan | False | 0.0 | nan | nan | False | 0 | NO_FINGER | 0 |  | 0 |  |  |  |  | 0 | 56 | 28 | 30 | 60 | 0.999310262130836 | 0.30000000000000004
2026-08-31T23:00:39.063 | 128478312 | P043 | rhythm_normal | NORMAL |  |  |  | 20 | 497995 | 2795 | 2267 | nan | nan | nan | nan | nan | nan | False | False | nan | False | 0.0 | nan | nan | False | 0 | NO_FINGER | 0 |  | 0 |  |  |  |  | 0 | 56 | 28 | 30 | 60 | 0.999310262130836 | 0.30000000000000004
2026-08-31T23:00:39.095 | 128478343 | P043 | rhythm_normal | NORMAL |  |  |  | 21 | 498035 | 2804 | 2275 | nan | nan | nan | nan | nan | nan | False | False | nan | False | 0.0 | nan | nan | False | 0 | NO_FINGER | 0 |  | 0 |  |  |  |  | 0 | 56 | 28 | 30 | 60 | 0.999310262130836 | 0.30000000000000004
2026-08-31T23:00:39.238 | 128478484 | P043 | rhythm_normal | NORMAL |  |  |  | 22 | 498075 | 2850 | 2315 | nan | nan | nan | nan | nan | nan | False | False | nan | False | 0.0 | nan | nan | False | 0 | NO_FINGER | 0 |  | 0 |  |  |  |  | 0 | 56 | 28 | 30 | 60 | 0.999529889498058 | 0.24494897427831783
2026-08-31T23:00:39.248 | 128478500 | P043 | rhythm_normal | NORMAL |  |  |  | 23 | 498115 | 2910 | 2356 | nan | nan | nan | nan | nan | nan | False | False | nan | False | 0.0 | nan | nan | False | 0 | NO_FINGER | 0 |  | 0 |  |  |  |  | 0 | 56 | 28 | 30 | 60 | 0.999529889498058 | 0.24494897427831783
2026-08-31T23:00:39.258 | 128478515 | P043 | rhythm_normal | NORMAL |  |  |  | 24 | 498155 | 2955 | 2375 | nan | nan | nan | nan | nan | nan | False | False | nan | False | 0.0 | nan | nan | False | 0 | NO_FINGER | 0 |  | 0 |  |  |  |  | 0 | 56 | 28 | 30 | 60 | 0.999529889498058 | 0.24494897427831783
2026-08-31T23:00:39.266 | 128478515 | P043 | rhythm_normal | NORMAL |  |  |  | 25 | 498195 | 2963 | 2386 | nan | nan | nan | nan | nan | nan | False | False | nan | False | 0.0 | nan | nan | False | 0 | NO_FINGER | 0 |  | 0 |  |  |  |  | 0 | 56 | 28 | 30 | 60 | 0.999529889498058 | 0.24494897427831783
2026-08-31T23:00:39.293 | 128478546 | P043 | rhythm_normal | NORMAL |  |  |  | 26 | 498235 | 2975 | 2394 | nan | nan | nan | nan | nan | nan | False | False | nan | False | 0.0 | nan | nan | False | 0 | NO_FINGER | 0 |  | 0 |  |  |  |  | 0 | 56 | 28 | 30 | 60 | 0.999529889498058 | 0.24494897427831783
2026-08-31T23:00:39.445 | 128478703 | P043 | rhythm_normal | NORMAL |  |  |  | 27 | 498275 | 2970 | 2400 | nan | nan | nan | nan | nan | nan | False | False | nan | False | 0.0 | nan | nan | False | 0 | NO_FINGER | 0 |  | 0 |  |  |  |  | 0 | 56 | 28 | 30 | 60 | 0.999310262130836 | 0.17320508075688776
2026-08-31T23:00:39.456 | 128478703 | P043 | rhythm_normal | NORMAL |  |  |  | 28 | 498315 | 2936 | 2352 | nan | nan | nan | nan | nan | nan | False | False | nan | False | 0.0 | nan | nan | False | 0 | NO_FINGER | 0 |  | 0 |  |  |  |  | 0 | 56 | 28 | 30 | 60 | 0.999310262130836 | 0.17320508075688776
2026-08-31T23:00:39.466 | 128478718 | P043 | rhythm_normal | NORMAL |  |  |  | 29 | 498355 | 2924 | 2324 | nan | nan | nan | nan | nan | nan | False | False | nan | False | 0.0 | nan | nan | False | 0 | NO_FINGER | 0 |  | 0 |  |  |  |  | 0 | 56 | 28 | 30 | 60 | 0.999310262130836 | 0.17320508075688776
2026-08-31T23:00:39.475 | 128478718 | P043 | rhythm_normal | NORMAL |  |  |  | 30 | 498395 | 2919 | 2320 | nan | nan | nan | nan | nan | nan | False | False | nan | False | 0.0 | nan | nan | False | 0 | NO_FINGER | 0 |  | 0 |  |  |  |  | 0 | 56 | 28 | 30 | 60 | 0.999310262130836 | 0.17320508075688776
2026-08-31T23:00:39.494 | 128478750 | P043 | rhythm_normal | NORMAL |  |  |  | 31 | 498435 | 2944 | 2348 | nan | nan | nan | nan | nan | nan | False | False | nan | False | 0.0 | nan | nan | False | 0 | NO_FINGER | 0 |  | 0 |  |  |  |  | 0 | 56 | 28 | 30 | 60 | 0.999310262130836 | 0.17320508075688776
2026-08-31T23:00:39.637 | 128478890 | P043 | rhythm_normal | NORMAL |  |  |  | 32 | 498475 | 2950 | 2352 | nan | nan | nan | nan | nan | nan | False | False | nan | False | 0.0 | nan | nan | False | 0 | NO_FINGER | 0 |  | 0 |  |  |  |  | 0 | 56 | 28 | 30 | 60 | 0.999310262130836 | 0.24494897427831783
2026-08-31T23:00:39.647 | 128478890 | P043 | rhythm_normal | NORMAL |  |  |  | 33 | 498515 | 2976 | 2360 | nan | nan | nan | nan | nan | nan | False | False | nan | False | 0.0 | nan | nan | False | 0 | NO_FINGER | 0 |  | 0 |  |  |  |  | 0 | 56 | 28 | 30 | 60 | 0.999310262130836 | 0.24494897427831783
2026-08-31T23:00:39.655 | 128478906 | P043 | rhythm_normal | NORMAL |  |  |  | 34 | 498555 | 2966 | 2353 | nan | nan | nan | nan | nan | nan | False | False | nan | False | 0.0 | nan | nan | False | 0 | NO_FINGER | 0 |  | 0 |  |  |  |  | 0 | 56 | 28 | 30 | 60 | 0.999310262130836 | 0.24494897427831783
2026-08-31T23:00:39.665 | 128478921 | P043 | rhythm_normal | NORMAL |  |  |  | 35 | 498595 | 2987 | 2359 | nan | nan | nan | nan | nan | nan | False | False | nan | False | 0.0 | nan | nan | False | 0 | NO_FINGER | 0 |  | 0 |  |  |  |  | 0 | 56 | 28 | 30 | 60 | 0.999310262130836 | 0.24494897427831783
2026-08-31T23:00:39.694 | 128478953 | P043 | rhythm_normal | NORMAL |  |  |  | 36 | 498635 | 2978 | 2351 | nan | nan | nan | nan | nan | nan | False | False | nan | False | 0.0 | nan | nan | False | 0 | NO_FINGER | 0 |  | 0 |  |  |  |  | 0 | 56 | 28 | 30 | 60 | 0.999310262130836 | 0.24494897427831783
2026-08-31T23:00:39.830 | 128479078 | P043 | rhythm_normal | NORMAL |  |  |  | 37 | 498675 | 2978 | 2365 | nan | nan | nan | nan | nan | nan | False | False | nan | False | 0.0 | nan | nan | False | 0 | NO_FINGER | 0 |  | 0 |  |  |  |  | 0 | 56 | 28 | 30 | 60 | 0.999310262130836 | 0.24494897427831783
2026-08-31T23:00:39.839 | 128479093 | P043 | rhythm_normal | NORMAL |  |  |  | 38 | 498715 | 3011 | 2386 | nan | nan | nan | nan | nan | nan | False | False | nan | False | 0.0 | nan | nan | False | 0 | NO_FINGER | 0 |  | 0 |  |  |  |  | 0 | 56 | 28 | 30 | 60 | 0.999310262130836 | 0.24494897427831783
2026-08-31T23:00:39.861 | 128479109 | P043 | rhythm_normal | NORMAL |  |  |  | 39 | 498755 | 3002 | 2378 | nan | nan | nan | nan | nan | nan | False | False | nan | False | 0.0 | nan | nan | False | 0 | NO_FINGER | 0 |  | 0 |  |  |  |  | 0 | 56 | 28 | 30 | 60 | 0.999310262130836 | 0.24494897427831783
2026-08-31T23:00:39.865 | 128479109 | P043 | rhythm_normal | NORMAL |  |  |  | 40 | 498795 | 3002 | 2376 | nan | nan | nan | nan | nan | nan | False | False | nan | False | 0.0 | nan | nan | False | 0 | NO_FINGER | 0 |  | 0 |  |  |  |  | 0 | 56 | 28 | 30 | 60 | 0.999310262130836 | 0.24494897427831783
2026-08-31T23:00:39.894 | 128479140 | P043 | rhythm_normal | NORMAL |  |  |  | 41 | 498835 | 3015 | 2381 | nan | nan | nan | nan | nan | nan | False | False | nan | False | 0.0 | nan | nan | False | 0 | NO_FINGER | 0 |  | 0 |  |  |  |  | 0 | 56 | 28 | 30 | 60 | 0.999310262130836 | 0.24494897427831783
2026-08-31T23:00:40.036 | 128479281 | P043 | rhythm_normal | NORMAL |  |  |  | 42 | 498875 | 3037 | 2402 | nan | nan | nan | nan | nan | nan | False | False | nan | False | 0.0 | nan | nan | False | 0 | NO_FINGER | 0 |  | 0 |  |  |  |  | 0 | 56 | 28 | 30 | 60 | 0.999310262130836 | 0.24494897427831783
2026-08-31T23:00:40.047 | 128479296 | P043 | rhythm_normal | NORMAL |  |  |  | 43 | 498915 | 3032 | 2399 | nan | nan | nan | nan | nan | nan | False | False | nan | False | 0.0 | nan | nan | False | 0 | NO_FINGER | 0 |  | 0 |  |  |  |  | 0 | 56 | 28 | 30 | 60 | 0.999310262130836 | 0.24494897427831783
2026-08-31T23:00:40.051 | 128479296 | P043 | rhythm_normal | NORMAL |  |  |  | 44 | 498955 | 3042 | 2396 | nan | nan | nan | nan | nan | nan | False | False | nan | False | 0.0 | nan | nan | False | 0 | NO_FINGER | 0 |  | 0 |  |  |  |  | 0 | 56 | 28 | 30 | 60 | 0.999310262130836 | 0.24494897427831783
2026-08-31T23:00:40.059 | 128479312 | P043 | rhythm_normal | NORMAL |  |  |  | 45 | 498995 | 3061 | 2422 | nan | nan | nan | nan | nan | nan | False | False | nan | False | 0.0 | nan | nan | False | 0 | NO_FINGER | 0 |  | 0 |  |  |  |  | 0 | 56 | 28 | 30 | 60 | 0.999310262130836 | 0.24494897427831783
2026-08-31T23:00:40.094 | 128479343 | P043 | rhythm_normal | NORMAL |  |  |  | 46 | 499035 | 3064 | 2419 | nan | nan | nan | nan | nan | nan | False | False | nan | False | 0.0 | nan | nan | False | 0 | NO_FINGER | 0 |  | 0 |  |  |  |  | 0 | 56 | 28 | 30 | 60 | 0.999310262130836 | 0.24494897427831783
2026-08-31T23:00:40.227 | 128479484 | P043 | rhythm_normal | NORMAL |  |  |  | 47 | 499075 | 3057 | 2410 | nan | nan | nan | nan | nan | nan | False | False | nan | False | 0.0 | nan | nan | False | 0 | NO_FINGER | 0 |  | 0 |  |  |  |  | 0 | 56 | 28 | 30 | 60 | 0.999529889498058 | 0.24494897427831783
2026-08-31T23:00:40.239 | 128479484 | P043 | rhythm_normal | NORMAL |  |  |  | 48 | 499115 | 3072 | 2422 | nan | nan | nan | nan | nan | nan | False | False | nan | False | 0.0 | nan | nan | False | 0 | NO_FINGER | 0 |  | 0 |  |  |  |  | 0 | 56 | 28 | 30 | 60 | 0.999529889498058 | 0.24494897427831783
2026-08-31T23:00:40.246 | 128479500 | P043 | rhythm_normal | NORMAL |  |  |  | 49 | 499155 | 3082 | 2448 | nan | nan | nan | nan | nan | nan | False | False | nan | False | 0.0 | nan | nan | False | 0 | NO_FINGER | 0 |  | 0 |  |  |  |  | 0 | 56 | 28 | 30 | 60 | 0.999529889498058 | 0.24494897427831783
2026-08-31T23:00:40.253 | 128479500 | P043 | rhythm_normal | NORMAL |  |  |  | 50 | 499195 | 3097 | 2446 | nan | nan | nan | nan | nan | nan | False | False | nan | False | 0.0 | nan | nan | False | 0 | NO_FINGER | 0 |  | 0 |  |  |  |  | 0 | 56 | 28 | 30 | 60 | 0.999529889498058 | 0.24494897427831783
2026-08-31T23:00:40.292 | 128479546 | P043 | rhythm_normal | NORMAL |  |  |  | 51 | 499235 | 3104 | 2452 | nan | nan | nan | nan | nan | nan | False | False | nan | False | 0.0 | nan | nan | False | 0 | NO_FINGER | 0 |  | 0 |  |  |  |  | 0 | 56 | 28 | 30 | 60 | 0.999529889498058 | 0.24494897427831783
2026-08-31T23:00:40.429 | 128479687 | P043 | rhythm_normal | NORMAL |  |  |  | 52 | 499275 | 3126 | 2449 | nan | nan | nan | nan | nan | nan | False | False | nan | False | 0.0 | nan | nan | False | 0 | NO_FINGER | 0 |  | 0 |  |  |  |  | 0 | 56 | 28 | 30 | 60 | 0.999310262130836 | 0.24494897427831783
2026-08-31T23:00:40.439 | 128479687 | P043 | rhythm_normal | NORMAL |  |  |  | 53 | 499315 | 3166 | 2477 | nan | nan | nan | nan | nan | nan | False | False | nan | False | 0.0 | nan | nan | False | 0 | NO_FINGER | 0 |  | 0 |  |  |  |  | 0 | 56 | 28 | 30 | 60 | 0.999310262130836 | 0.24494897427831783
2026-08-31T23:00:40.450 | 128479703 | P043 | rhythm_normal | NORMAL |  |  |  | 54 | 499355 | 3199 | 2508 | nan | nan | nan | nan | nan | nan | False | False | nan | False | 0.0 | nan | nan | False | 0 | NO_FINGER | 0 |  | 0 |  |  |  |  | 0 | 56 | 28 | 30 | 60 | 0.999310262130836 | 0.24494897427831783
2026-08-31T23:00:40.455 | 128479703 | P043 | rhythm_normal | NORMAL |  |  |  | 55 | 499395 | 3214 | 2514 | nan | nan | nan | nan | nan | nan | False | False | nan | False | 0.0 | nan | nan | False | 0 | NO_FINGER | 0 |  | 0 |  |  |  |  | 0 | 56 | 28 | 30 | 60 | 0.999310262130836 | 0.24494897427831783
2026-08-31T23:00:40.493 | 128479750 | P043 | rhythm_normal | NORMAL |  |  |  | 56 | 499435 | 3231 | 2527 | nan | nan | nan | nan | nan | nan | False | False | nan | False | 0.0 | nan | nan | False | 0 | NO_FINGER | 0 |  | 0 |  |  |  |  | 0 | 56 | 28 | 30 | 60 | 0.999310262130836 | 0.24494897427831783
2026-08-31T23:00:40.632 | 128479890 | P043 | rhythm_normal | NORMAL |  |  |  | 57 | 499475 | 3234 | 2529 | nan | nan | nan | nan | nan | nan | False | False | nan | False | 0.0 | nan | nan | False | 0 | NO_FINGER | 0 |  | 0 |  |  |  |  | 0 | 56 | 28 | 30 | 60 | 0.999310262130836 | 0.17320508075688776
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

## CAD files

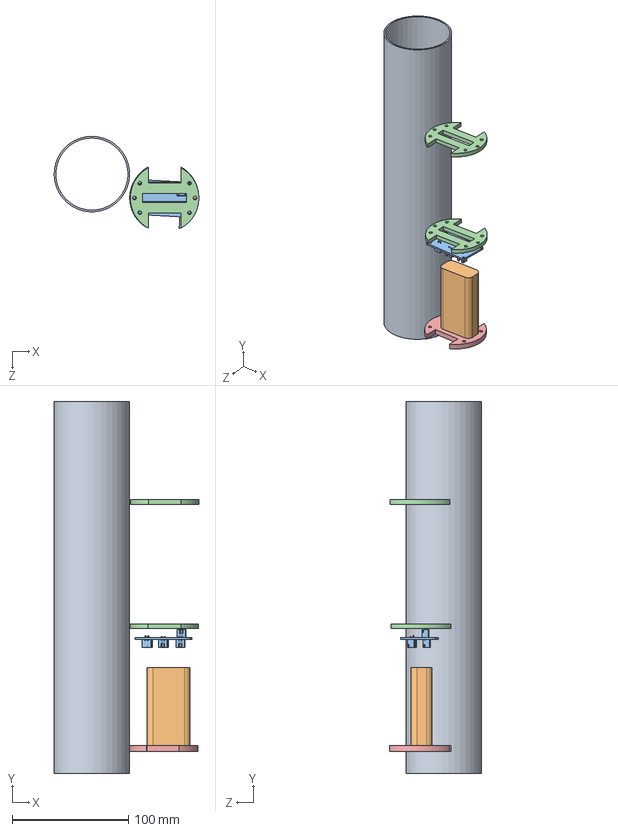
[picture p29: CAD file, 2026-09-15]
mechanical/电路连接件/装配体2.SLDASM
124.5 x 320.0 x 79.4 mm
电池底座
主板底座 x 2
POWER
06_电池
01_亚克力筒

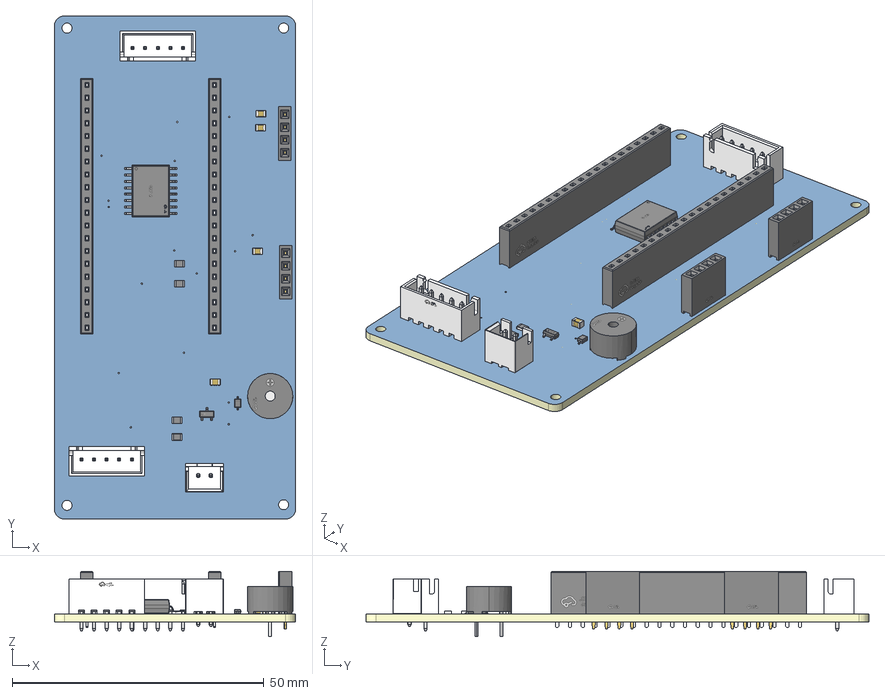
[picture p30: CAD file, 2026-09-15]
mechanical/MAIN.step
48.0 x 100.0 x 13.0 mm
Board~eNEB
TopCopper~eNEB
BottomCopper~eNEB
TopFpcStiffener~eNEB
BottomFpcStiffener~eNEB
R0805~R0805_L2.0-W1.3-H0.6~WNp5 x 4
SOD-323_L1.8-W1.3-LS2.5-RD~SOD-323_L1.8-W1.3-LS2.5-RD~9gm5
C0805~C0805_L2.0-W1.3-H1.3~fmRj x 4
CONN-TH_B2B-XH-A-LF-SN~XH2.5-2A~urJf
SOIC-16_L10.3-W7.5-P1.27-LS10.3-BL~SOIC-16_L10.3-W7.5-H2.7-LS10.3-P1.27~hbBc
CONN-TH_5P-P2.50_ZX-XH2.54-5PZZ~CONN-TH_5P-P2.50_ZX-XH2.54-5PZZ~6J9V x 2
BUZ-TH_BD9.6-P5.00-D0.7-FD~BUZ-TH_D9.0-H5.5-P5.0~Yugg
HDR-TH_4P-P2.54-V-F~HDR-TH_4P-P2.54-V-F~Cd4S x 2
HDR-TH_20P-P2.54-V-F-2~HDR-TH_20P-P2.54-V-F-2~kXCm x 2
SOT-23-3_L2.9-W1.3-P1.90-LS2.4-BR~SOT-23-3P_L2.9-W1.3-H1.0-LS2.4-P0.95~J6Xy

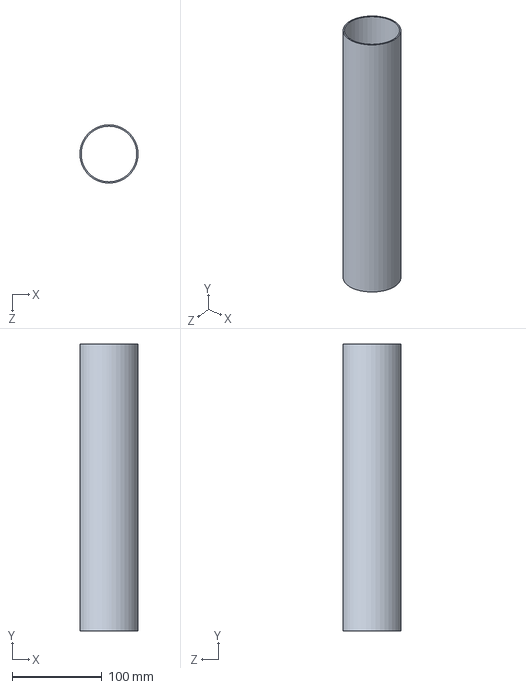
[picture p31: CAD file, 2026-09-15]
mechanical/01_亚克力筒.SLDPRT
64.9 x 320.0 x 65.0 mm

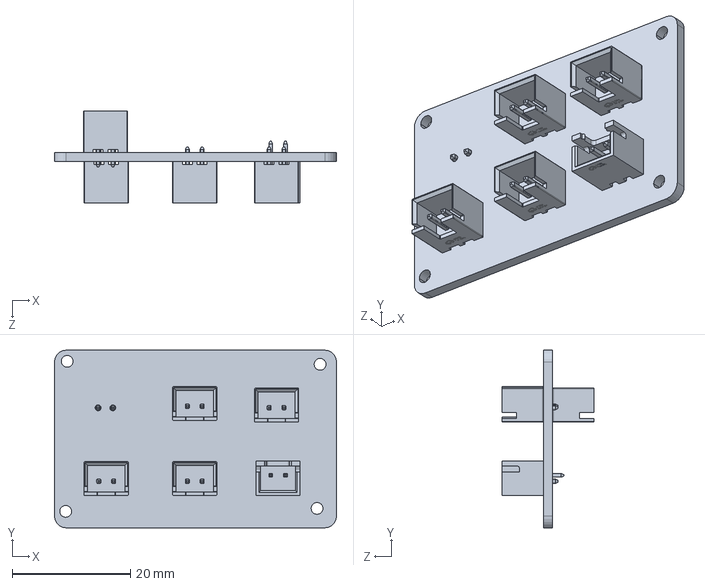
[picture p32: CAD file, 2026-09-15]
mechanical/电路连接件/POWER.SLDPRT
47.7 x 30.1 x 15.6 mm

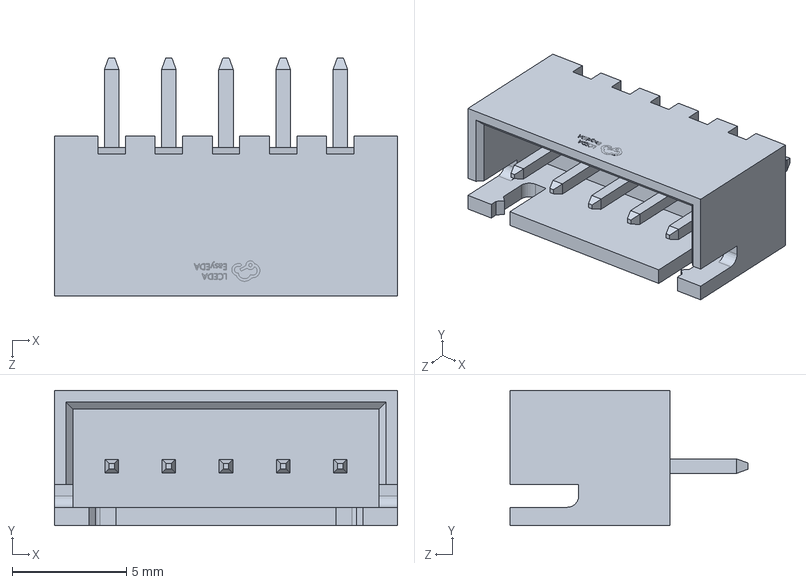
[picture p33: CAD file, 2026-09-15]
mechanical/CONN-TH_5P-P2.50_ZX-XH2.54-5PZZ~CONN-TH_5P-P2.50_ZX-XH2.54-5PZZ~SCej.step.SLDPRT
15.0 x 5.91 x 10.4 mm

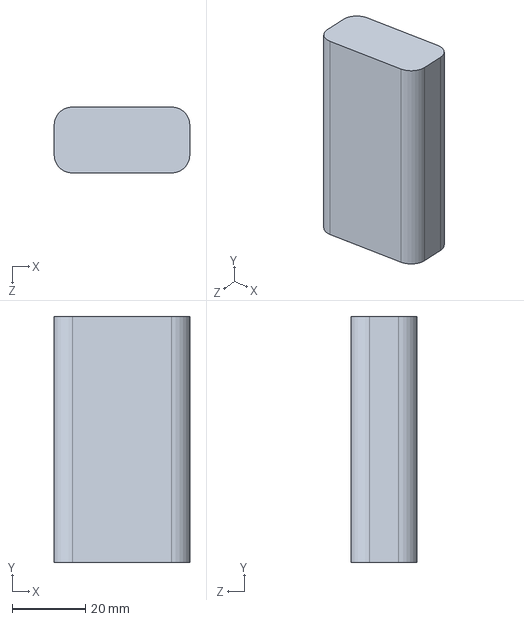
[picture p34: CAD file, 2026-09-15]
mechanical/电路连接件/06_电池.SLDPRT
37.0 x 67.0 x 18.0 mm

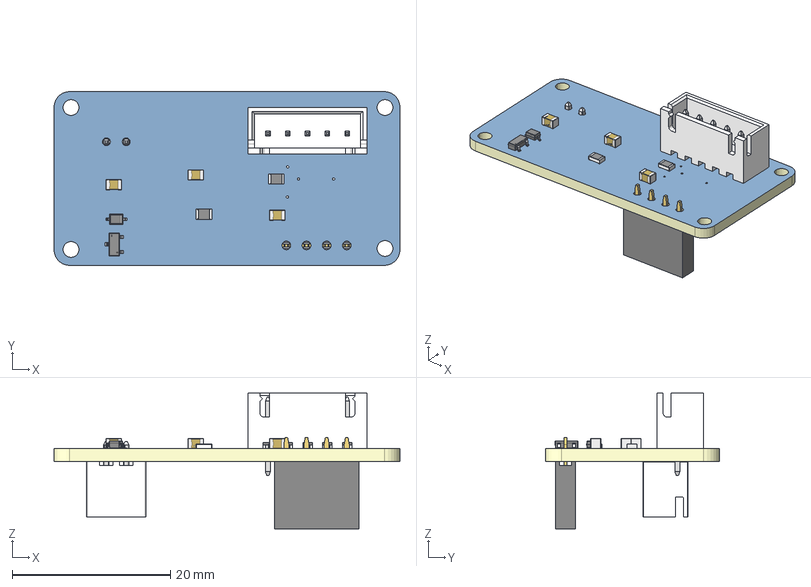
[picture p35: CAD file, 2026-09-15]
mechanical/LOWER.step
43.7 x 21.9 x 17.1 mm
Board~h9wq
TopCopper~h9wq
BottomCopper~h9wq
TopFpcStiffener~h9wq
BottomFpcStiffener~h9wq
R0805~R0805_L2.0-W1.3-H0.6~eU9x x 2
CONN-TH_B2B-XH-A-LF-SN~XH2.5-2A~C20Y
CONN-TH_5P-P2.50_ZX-XH2.54-5PZZ~CONN-TH_5P-P2.50_ZX-XH2.54-5PZZ~SCej
SOD-323_L1.8-W1.3-LS2.5-RD~SOD-323_L1.8-W1.3-LS2.5-RD~BgIR
C0805~C0805_L2.0-W1.3-H1.3~p9s3 x 3
SOT-23-3_L2.9-W1.3-P1.90-LS2.3-BR~SOT-23-3_L2.9-W1.3-P1.90-LS2.3-BR~2XC3
HDR-TH_4P-P2.54-V-F~HDR-TH_4P-P2.54-V-F~jD7v

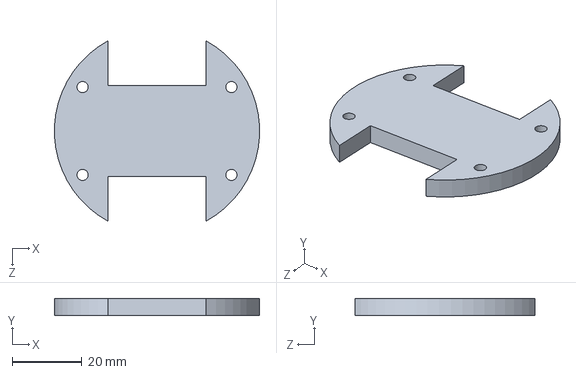
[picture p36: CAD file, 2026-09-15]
mechanical/电路连接件/电池底座.SLDPRT
58.9 x 5.00 x 51.8 mm

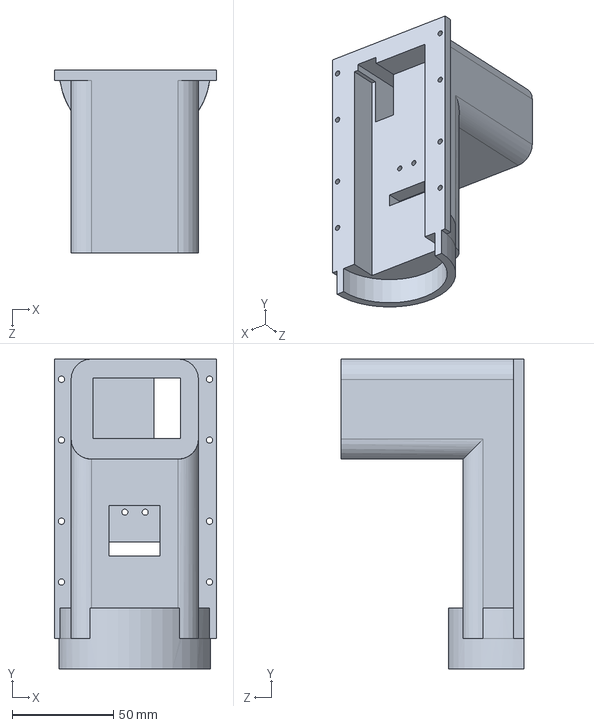
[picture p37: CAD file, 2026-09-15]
mechanical/02_摄像头和灯泡载体.SLDPRT
80.0 x 152.9 x 90.0 mm

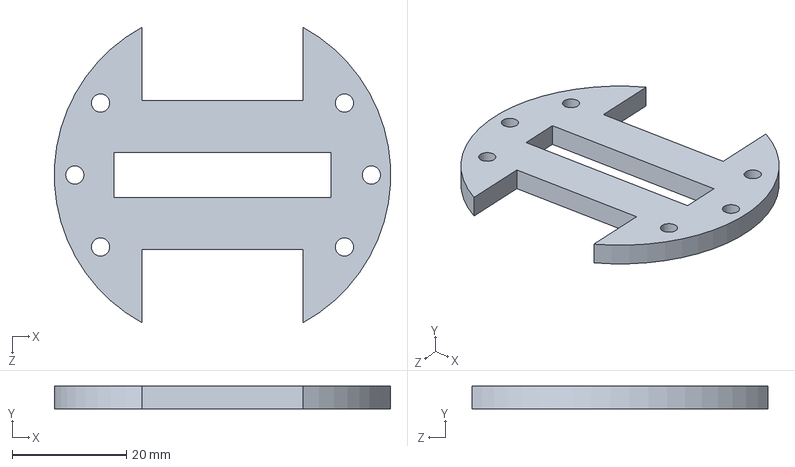
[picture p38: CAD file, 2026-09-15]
mechanical/电路连接件/主板底座.SLDPRT
58.9 x 4.00 x 51.8 mm

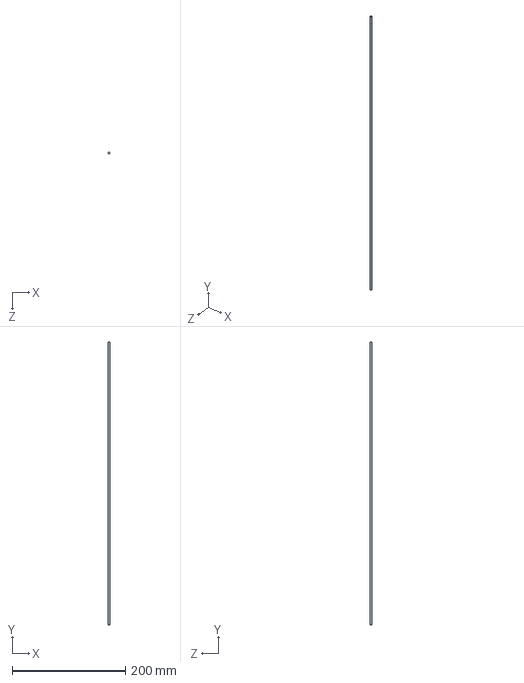
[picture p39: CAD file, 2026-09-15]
mechanical/08_螺柱.SLDPRT
3.50 x 500.0 x 3.50 mm

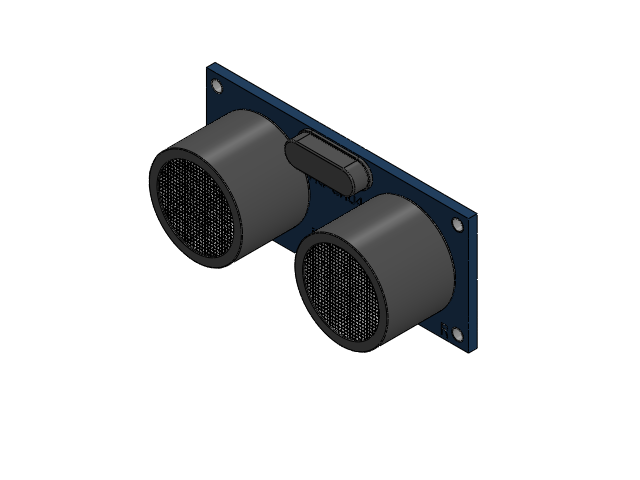
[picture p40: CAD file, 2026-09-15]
mechanical/User Library-hc-sr04-2.SLDASM
User Library-hc-sr04-2_Quarz.step
User Library-hc-sr04-2_Platine.step
User Library-hc-sr04-2_Pins_4fach_90Grad_001.step
User Library-hc-sr04-2_HC_SR04_gitter_001.step
User Library-hc-sr04-2_HC_SR04_gitter_002.step

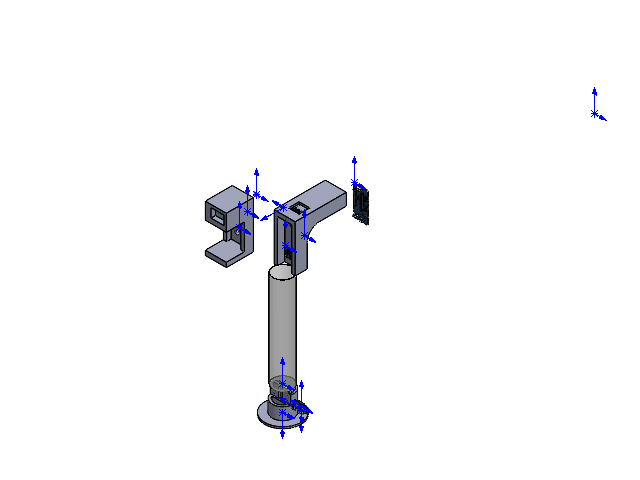
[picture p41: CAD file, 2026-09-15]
mechanical/装配体.SLDASM
01_亚克力筒
02_摄像头和灯泡载体
03_灯泡
04_上半后部分
05_下半部分
User Library-hc-sr04-2_Quarz.step
User Library-hc-sr04-2_Platine.step
User Library-hc-sr04-2_Pins_4fach_90Grad_001.step
User Library-hc-sr04-2_HC_SR04_gitter_001.step
User Library-hc-sr04-2_HC_SR04_gitter_002.step
User Library-128x64I2COLEDDisplayAdafruit
MAINSLDPRT
UPPER.step x 2

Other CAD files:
mechanical/User Library-hc-sr04-2_hc-sr04.step.SLDASM
mechanical/MAINSLDPRT.SLDPRT
mechanical/User Library-hc-sr04-2_Platine.step.SLDPRT
mechanical/电路连接件/01_亚克力筒.SLDPRT
mechanical/电路连接件/LOWERSLDPRT.SLDPRT
mechanical/02_摄像头和灯泡载体.3mf
mechanical/02_摄像头和灯泡载体.STL
mechanical/02_摄像头和灯泡载体.gcode.3mf
mechanical/03_灯泡.SLDPRT
mechanical/04_上半后部分.SLDPRT
mechanical/04_上半后部分.STL
mechanical/05_下半部分.3mf
mechanical/05_下半部分.SLDPRT
mechanical/05_下半部分.STL
mechanical/06_电池.SLDPRT
mechanical/07_电池底座.SLDPRT
mechanical/C0805~C0805_L2.0-W1.3-H1.3~p9s3.step.SLDPRT
mechanical/POWER.step
mechanical/SOD-323_L1.8-W1.3-LS2.5-RD~SOD-323_L1.8-W1.3-LS2.5-RD~BgIR.step.SLDPRT
mechanical/UPPER.step
mechanical/User Library-128x64I2COLEDDisplayAdafruit.sldprt
mechanical/User Library-hc-sr04-2_HC_SR04_gitter_001.step.SLDPRT
mechanical/User Library-hc-sr04-2_HC_SR04_gitter_002.step.SLDPRT
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

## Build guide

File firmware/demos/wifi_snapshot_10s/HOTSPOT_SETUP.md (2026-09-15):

# 手机热点联网说明

本 Demo 支持两种工作方式：

1. 手机热点 / 路由器模式（推荐）：ESP32 和电脑都连接同一个 2.4GHz 网络。电脑保持互联网，Qt 使用 ESP32 串口打印出的局域网 IP 收图。
2. 独立热点模式：ESP32 建立 `ESP32-CAM-10S`，电脑直连 `192.168.4.1`。此模式没有互联网出口，Windows 显示“无 Internet”是正常的。

## 配置手机热点

本机私有热点配置位于 `firmware/include/DemoSecrets.h`，该文件已被 `firmware/.gitignore` 排除，不能提交到代码仓库。

```cpp
namespace DemoSecrets {
constexpr char WIFI_SSID[] = "你的热点名称";
constexpr char WIFI_PASSWORD[] = "你的热点密码";
}
```

手机热点必须启用 **2.4GHz**。ESP32-S3 不能使用纯 5GHz 热点。

## 烧录和运行

烧录后，以 115200 波特率打开串口。连接成功时会出现：

```text
[WiFi] router connected: 192.168.x.x
[HTTP] open http://192.168.x.x/
```

将这个 IP 填给 Qt 上位机：

```powershell
python pc/qt_receiver.py --url http://192.168.x.x --interval 10
```

若 12 秒内连接失败，固件会自动回退到独立热点模式，串口会打印回退提示和 `192.168.4.1`。

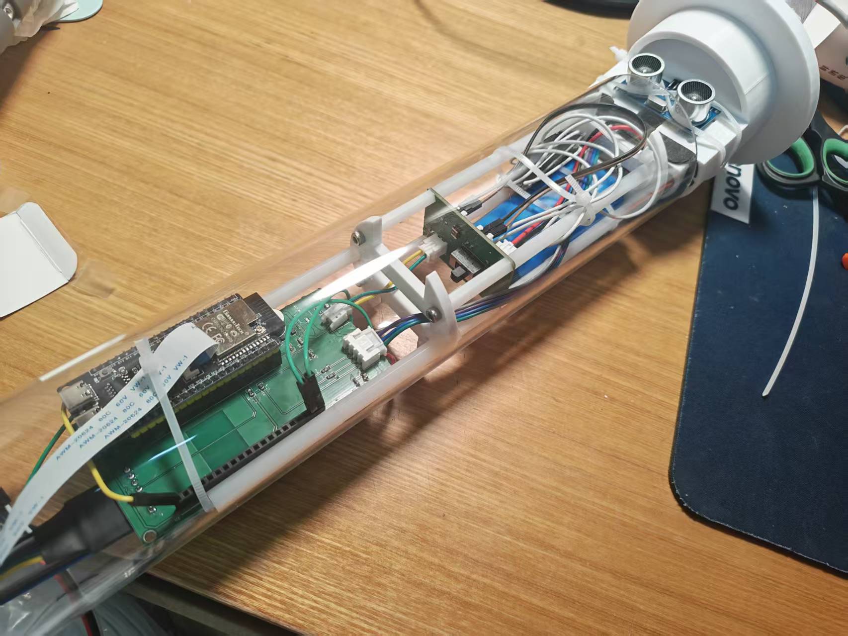
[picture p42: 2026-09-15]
media/structure/assembly-2.jpg

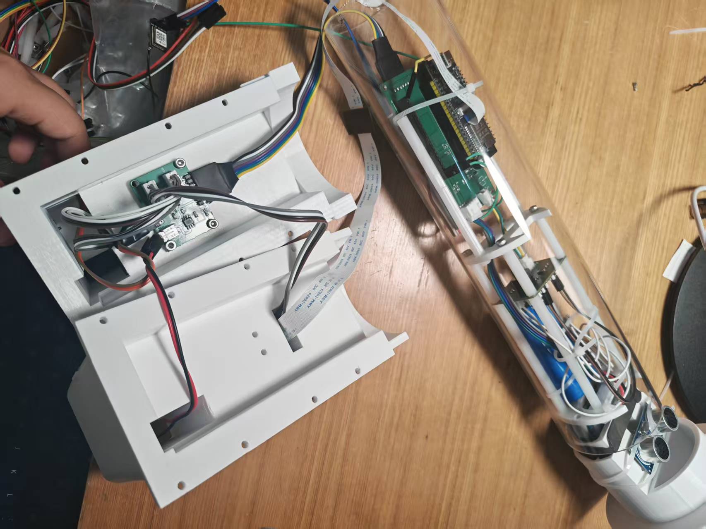
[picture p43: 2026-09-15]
media/structure/assembly-1.jpg

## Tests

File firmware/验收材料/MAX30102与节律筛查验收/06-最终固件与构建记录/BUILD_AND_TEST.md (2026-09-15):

# 最终固件构建与测试记录

## 构建环境

- PlatformIO 环境：`esp32-s3-cam`；
- Platform：Espressif32 7.0.1；
- Framework：Arduino ESP32 3.20017；
- Board：ESP32-S3-DevKitC-1-N8；
- 构建模式：release。

## 构建命令

```powershell
platformio run -e esp32-s3-cam
```

## 最终资源占用

```text
RAM  : 55308 / 327680 bytes（16.9%）
Flash: 1012877 / 1966080 bytes（51.5%）
```

构建成功并生成 `SmartCane-MAX30102-final.bin`。该二进制包含峰值突出度、自适应不应期、
IBI 中位数 HR、长间隔历史清空和心搏新鲜度保护。

## Qt回归测试

```powershell
python -m unittest discover -s tests -v
```

结果：21 项测试全部通过，覆盖串口选择、自检诊断、IMU/PPG CSV、协议解析、摄像头分块和
地图轨迹解析。

## 实机最终验证

固件烧录后采集 P041～P043。三组均保持 25 Hz、零丢帧、零 FIFO 溢出；243 个有效
IBI 中没有小于 500 ms 或大于 1200 ms 的间隔；29 次端侧推理全部输出 `NORMAL`。

## 安全说明

完整 `UserConfig.h` 可能包含网络和 MQTT 配置，因此没有进入验收包。包内
`03-固件关键代码/UserConfig_MAX30102节选.h` 仅保留与本模块有关的脱敏参数。

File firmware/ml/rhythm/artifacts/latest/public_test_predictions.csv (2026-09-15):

subject_id | label | window_end_s | float_probability_af | int8_probability_af | float_prediction | int8_prediction
AF_004 | 1 | 15.0 | 0.8901199315784546 | 0.8896395925238035 | 1 | 1
AF_004 | 1 | 20.0 | 0.8726034292820616 | 0.8726017386755344 | 1 | 1
AF_004 | 1 | 30.0 | 0.8974850151779511 | 0.8970068159272235 | 1 | 1
AF_004 | 1 | 35.0 | 0.9026500452959637 | 0.9021001776543803 | 1 | 1
AF_004 | 1 | 40.0 | 0.8974850151779511 | 0.8970068159272235 | 1 | 1
AF_004 | 1 | 45.0 | 0.887788072584166 | 0.8873659858249006 | 1 | 1
AF_004 | 1 | 50.0 | 0.8671020332114793 | 0.8667496964321619 | 1 | 1
AF_004 | 1 | 55.0 | 0.8678781623294022 | 0.8677262755846212 | 1 | 1
AF_004 | 1 | 60.0 | 0.905823908385357 | 0.905441090940671 | 1 | 1
AF_004 | 1 | 65.0 | 0.8908440754823997 | 0.8904209403524267 | 1 | 1
AF_004 | 1 | 70.0 | 0.8974850151779511 | 0.8970068159272235 | 1 | 1
AF_004 | 1 | 75.0 | 0.8974850151779511 | 0.8970068159272235 | 1 | 1
AF_004 | 1 | 80.0 | 0.9076842472451865 | 0.9072620548030383 | 1 | 1
AF_004 | 1 | 85.0 | 0.8854814097889135 | 0.8850008216501081 | 1 | 1
AF_004 | 1 | 90.0 | 0.8885923495834271 | 0.8881118374674158 | 1 | 1
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

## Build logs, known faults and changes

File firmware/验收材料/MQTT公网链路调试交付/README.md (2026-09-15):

# SmartCane MQTT 公网链路调试交付包

整理日期：2026-08-31  
设备标识：`device01`  
验收范围：ESP32-S3-CAM → MQTT over TLS → MQTTX / 远程监护网页

## 1. 交付结论

本次已经完成 MQTT 公网上行主链路调试，不只是制作了一个网页和两张展示图。交付内容还包括：

- ESP32 端 MQTT over TLS 发布、NTP 校时、在线状态、自动重连与事件队列代码；
- `telemetry`、`vitals`、`gps`、`event`、`presence` 五类 Topic；
- MQTTX 的 TLS 配置、周期消息接收和 SOS 事件实测截图；
- 可运行的只读远程监护网页源码及自动化测试；
- 2026-08-31 11:24—11:51 的原始串口日志；
- PlatformIO 构建配置及固件安全交付说明；
- 脱敏配置模板、Topic 协议和复现步骤。

已有证据足以说明以下核心功能已打通：

1. 设备通过 TLS 端口 8883 连接公网 Broker；
2. MQTTX 能接收设备的周期遥测、生命体征和 GPS 消息；
3. SOS 能立即发布到 `smartcane/device01/event`，QoS 为 1；
4. 网页能从公网 MQTT 实时显示设备在线、正常状态、生命体征和 SOS；
5. 远程命令保持关闭，网页为只读监护端。

生产环境发布前仍应补做跨运营商网络、强制断网重连、遗嘱离线状态、全部事件类型和长时间稳定性测试。它们在代码中已有支持，但当前交付证据不足以声称全部实测通过。

## 2. 目录说明

| 目录 | 内容 |
|---|---|
| `01-验收截图` | MQTTX 配置、周期消息、SOS 事件、网页正常/SOS 状态 |
| `02-远程监护网页源码` | Flask + Paho MQTT + SSE 网页，含测试和启动脚本 |
| `03-固件MQTT代码` | MQTT 服务及其在主应用中的集成代码快照 |
| `04-串口日志` | MQTT 联调时的原始 TTL 串口日志和关键记录 |
| `05-协议与验收文档` | Topic 表、复现步骤、结论及未覆盖项 |
| `06-固件构建说明` | PlatformIO 构建配置及二进制凭据安全说明 |

## 3. 核心验收证据

### 3.1 MQTTX 连接及消息接收

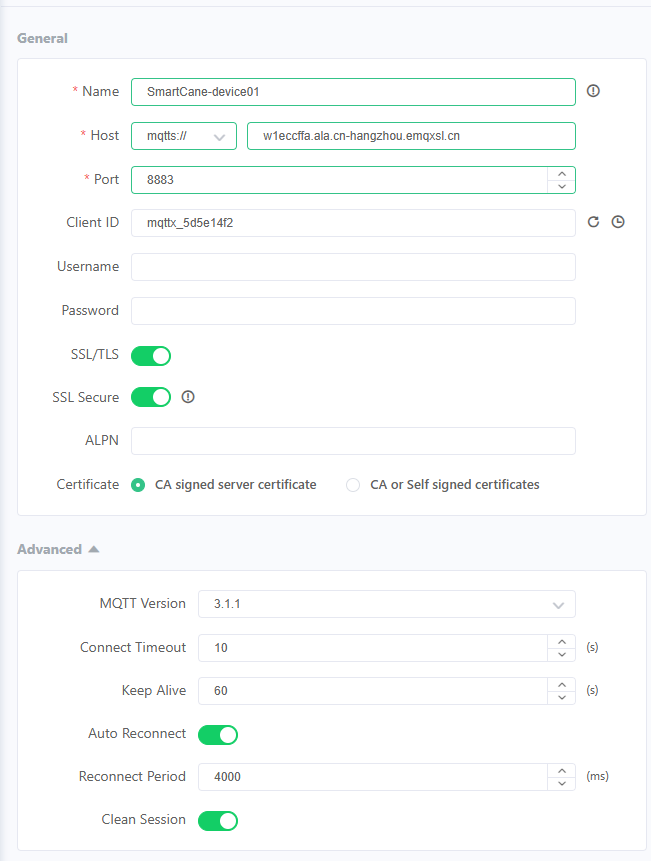
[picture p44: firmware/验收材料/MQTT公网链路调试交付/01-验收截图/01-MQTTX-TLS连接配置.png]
MQTTX TLS 配置


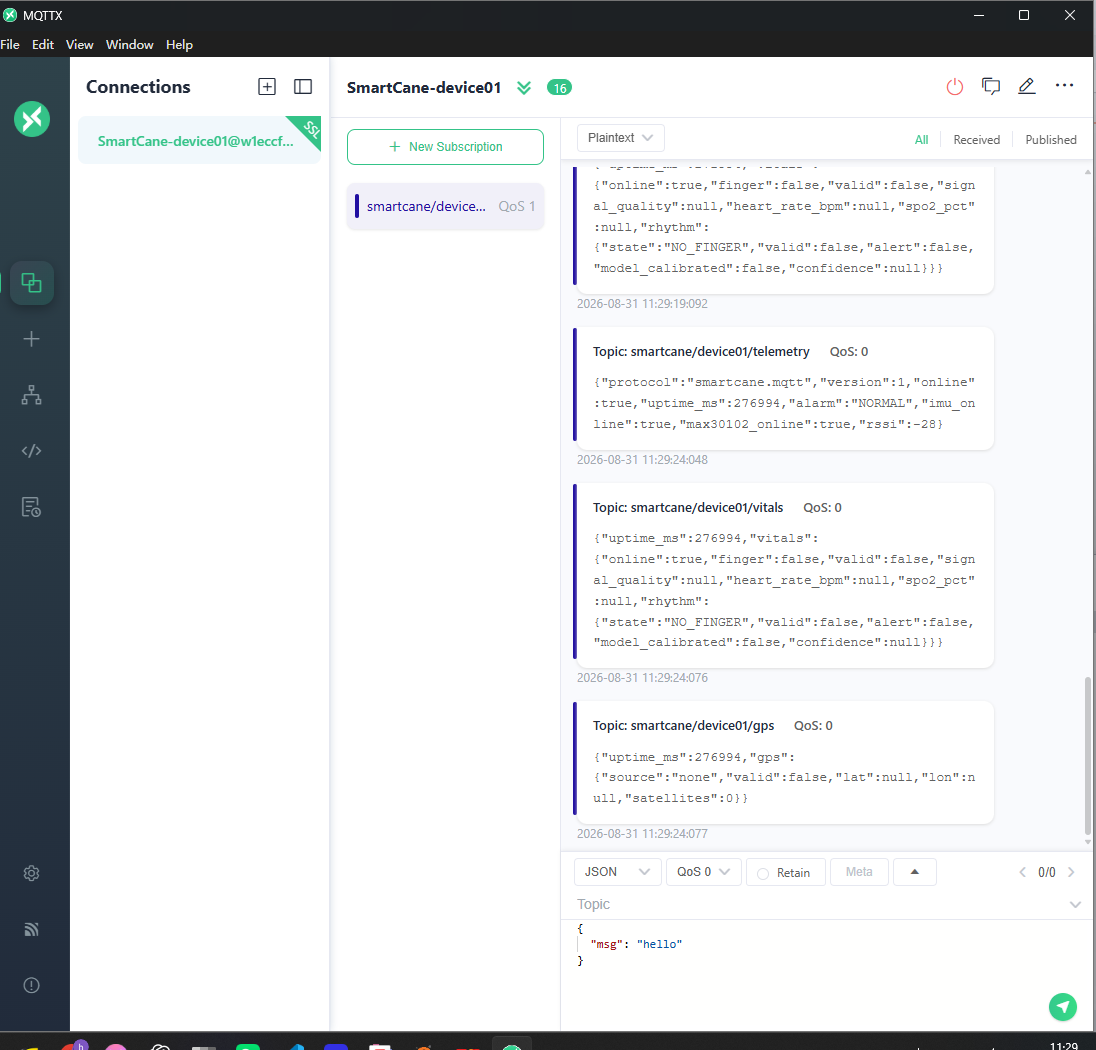
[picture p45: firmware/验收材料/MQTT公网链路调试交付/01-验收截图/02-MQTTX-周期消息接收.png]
MQTTX 周期消息


### 3.2 SOS 事件

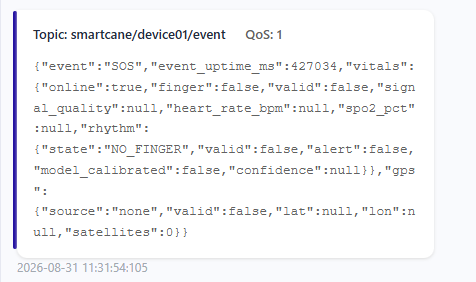
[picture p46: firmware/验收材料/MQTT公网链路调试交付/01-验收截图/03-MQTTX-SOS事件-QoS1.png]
MQTTX SOS 事件


截图证明 `smartcane/device01/event` 收到 `event=SOS`，消息 QoS 为 1，并携带事件时刻、生命体征与 GPS 快照。

### 3.3 远程监护网页

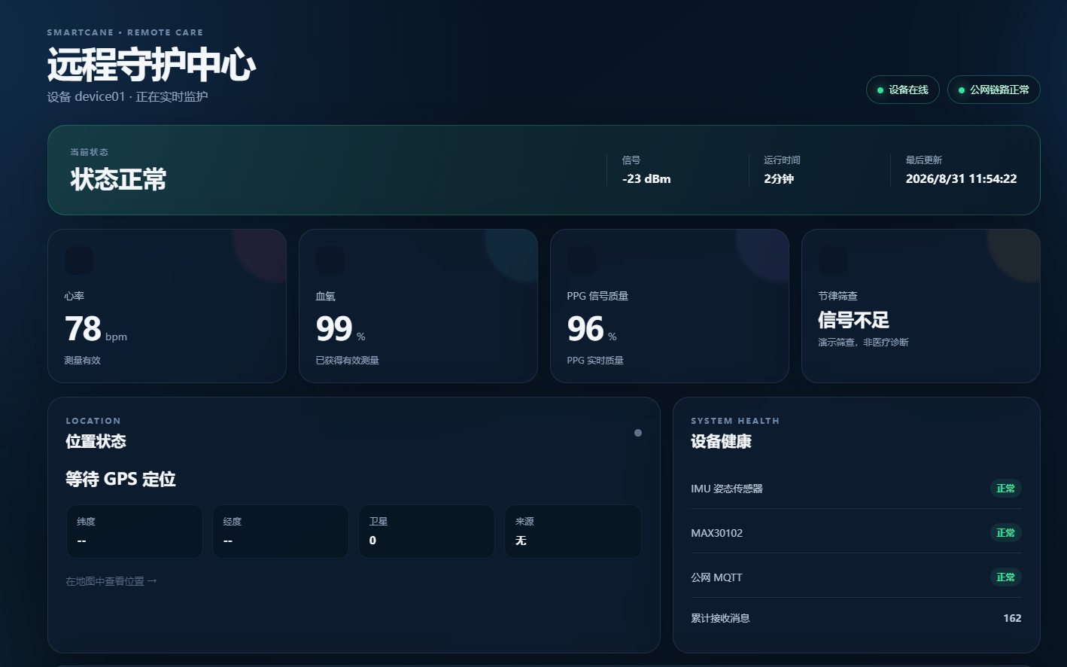
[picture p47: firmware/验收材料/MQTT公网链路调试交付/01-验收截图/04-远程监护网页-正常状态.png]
网页正常状态


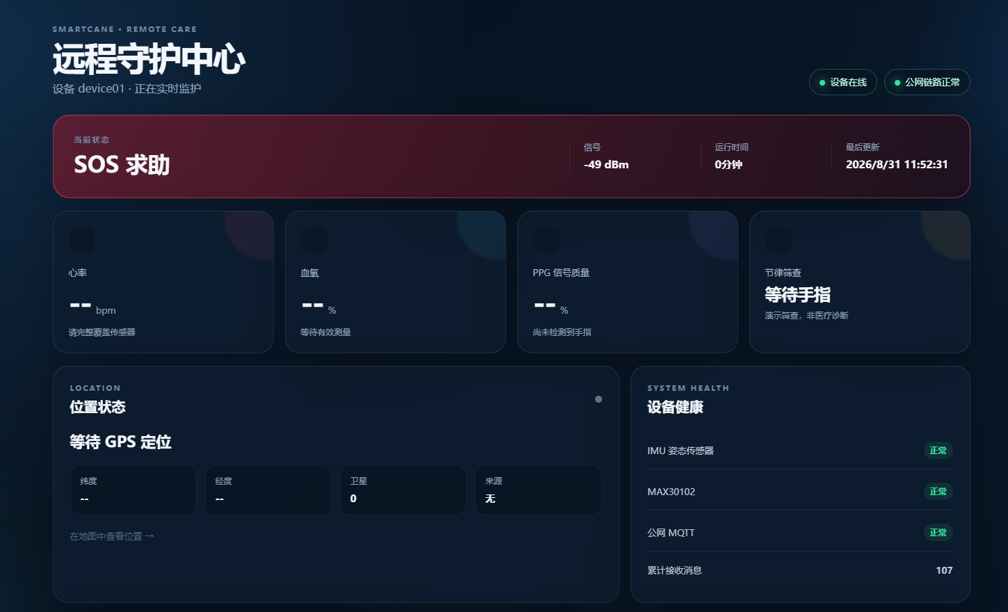
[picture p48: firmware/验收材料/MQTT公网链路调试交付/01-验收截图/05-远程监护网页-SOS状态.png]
网页 SOS 状态


网页正常状态截图显示心率 78 bpm、血氧 99%、PPG 质量 96%，设备和公网 MQTT 均为正常；SOS 截图显示远程页面能切换到求助状态。

## 4. 快速复现

1. 阅读 `05-协议与验收文档/MQTT调试复现与验收步骤.md`。
2. 按 `02-远程监护网页源码/.env.example` 创建本机 `.env`，填写只读 MQTT 账号。
3. 在网页源码目录运行 `run.ps1 -Install`，再运行 `run.ps1`。
4. MQTTX 订阅 `smartcane/device01/#`，确认周期消息与 SOS 事件。
5. 需要重新构建和烧录时，先阅读 `06-固件构建说明`；不要公开分发含真实 MQTT 凭据的固件二进制。

## 5. 安全说明

- 本交付包未复制主工程中的真实 `UserConfig.h`，网页 `.env` 也未纳入归档；
- 所有配置文件仅保留占位符，不能直接用于连接实际 Broker；
- Broker 域名可能出现在验收截图和原始串口日志中，但用户名、密码未写入交付文档；
- 远程命令当前为 `false`，在完成 Topic ACL、独立账号和权限限制前不要开启；
- 若交付包要公开上传，仍建议先检查截图中的 Broker 域名是否需要遮挡。

## 6. 验证记录

- 远程网页单元测试：7 项全部通过；
- 原始日志中可见 MQTT 从 `CONNECTING` 进入 `ONLINE`；
- 截图中可见 MQTTX 的周期 Topic 和 QoS 1 SOS；
- 详细边界见 `05-协议与验收文档/测试结论与未覆盖项.md`。

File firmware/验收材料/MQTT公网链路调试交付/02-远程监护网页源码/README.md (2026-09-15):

# SmartCane 远程守护网页

这是面向实际公网使用的只读仪表盘：后端通过 MQTT over TLS 订阅设备消息，浏览器通过 HTTPS/SSE 查看实时状态。MQTT 密码只存在服务器环境变量中，不会发送到浏览器；当前版本没有远程控制入口。

## 本机启动

```powershell
cd remote_dashboard
Copy-Item .env.example .env
```

编辑 `.env`，填写 MQTT 账号。建议在 EMQX 创建只能订阅 `smartcane/device01/#` 的只读账号，不要长期复用设备发布账号。

首次运行：

```powershell
.\run.ps1 -Install
.\run.ps1
```

浏览器打开 `http://127.0.0.1:8080`。不连接实际 Broker 的界面演示：

```powershell
.\run.ps1 -Demo
```

## 公网部署要求

1. 部署在持续运行的云服务器、容器平台或 NAS 上；事件 Topic 不保留，后端只有持续在线才能完整接收事件。
2. 设置 `WEB_HOST=0.0.0.0` 时，程序会强制要求 `DASHBOARD_USERNAME` 和 `DASHBOARD_PASSWORD`。
3. 使用 Caddy、Nginx 或平台自带网关提供 HTTPS，不要直接将 8080 明文端口暴露到公网。
4. MQTT 账号只允许订阅本设备 Topic，禁止发布和订阅 `command`。
5. `.env` 已被 `.gitignore` 排除，禁止提交密码。

Docker 示例：

```powershell
docker build -t smartcane-remote .
docker run --rm -p 127.0.0.1:8080:8080 --env-file .env smartcane-remote
```

公网反向代理需要关闭响应缓冲，确保 `/api/stream` 的 SSE 实时推送不会被缓存。例如 Nginx 对该路径设置 `proxy_buffering off`。

## 页面状态判定

- `presence=online` 且 telemetry 15 秒内更新：设备在线。
- telemetry 超过 15 秒未更新：设备离线或链路异常。
- `event` 使用 QoS 1，显示 SOS、疑似跌倒、跌倒和节律筛查事件。
- GPS 无定位时显示等待，不会把 `null` 坐标误认为故障位置。

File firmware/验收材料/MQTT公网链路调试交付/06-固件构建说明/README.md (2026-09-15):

# 固件构建说明与安全边界

构建环境：PlatformIO `esp32-s3-cam`  
目标板：`esp32-s3-devkitc-1`，8 MB Flash，OPI PSRAM  
已验证的当前整合固件构建时间：2026-08-31 18:09—18:10

| 文件 | 用途 |
|---|---|
| `platformio.ini` | 板型、Flash、PSRAM、串口及构建目录配置 |

交付包没有附带 `firmware.bin`、`bootloader.bin` 和 `partitions.bin`。原因是当前主工程把 MQTT 设备账号和密码作为编译常量写入 `UserConfig.h`，生成的主固件会携带这些凭据；公开归档该二进制并不安全。

需要烧录时，应在受控电脑上使用完整主工程重新构建，再通过 PlatformIO 的 Upload 执行烧录。当前整合固件包含 MQTT 功能以及当天稍后完成的 IMU 阈值调整，它也不是 11:24 MQTT 首次联调版本的逐字节历史快照。

后续建议把设备凭据迁移到不提交版本库的私有配置、NVS 配置区或部署时注入机制，并为每台设备分配独立账号和 Topic ACL。

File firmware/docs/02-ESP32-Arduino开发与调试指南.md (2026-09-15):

# ESP32-S3 Arduino 开发与调试指南（零基础）

## 1. 这份指南解决什么问题

本文以本工程的 ESP32-S3-CAM 为对象，带你完成从“能看懂工程”到“能编译、烧录、看日志、定位故障和安全修改功能”的完整流程。

不要求读者提前掌握单片机、Arduino、C++ 或 PlatformIO。建议第一次严格按顺序操作，不要一开始就同时连接所有传感器。

工程内部设计和逐文件职责见 [01-工程架构与文件说明.md](./01-工程架构与文件说明.md)。

## 2. 先理解 10 个基本概念

| 概念 | 通俗解释 |
|---|---|
| ESP32-S3 | 一颗带 Wi-Fi、蓝牙、USB、多个串口和丰富 GPIO 的微控制器。 |
| 开发板 | 把 ESP32-S3、Flash、PSRAM、USB、电源和排针做在一起的板卡。 |
| Arduino 框架 | 用 `setup()`、`loop()` 和常用库简化嵌入式开发的软件框架。 |
| PlatformIO | 负责下载编译器和框架、管理开发板、编译、上传和串口监视。 |
| 固件 | 编译后写入 ESP32-S3 Flash 的程序，本工程产物为 `firmware.bin`。 |
| GPIO | 可作为输入或输出的引脚；ESP32-S3 只能承受 3.3 V 逻辑。 |
| I2C | 两根信号线连接多个低速设备的总线，设备靠地址区分。 |
| UART | TX/RX 两根数据线组成的串口，常用于 GPS、IMU 和调试。 |
| 串口监视器 | 在电脑上查看 ESP32 输出日志的窗口，是零基础调试最重要的工具。 |
| BOOT/RST | BOOT 用于进入下载模式，RST/EN 用于复位芯片。 |

## 3. 本机已配置的开发环境

当前工程采用以下组合：

- VS Code；
- PlatformIO IDE 扩展；
- PlatformIO Core；
- Espressif32 开发平台；
- Arduino for ESP32 框架；
- Xtensa ESP32-S3 编译器；
- `esptool` 烧录工具。

PlatformIO IDE 自带 PlatformIO Core，不需要另外安装 Arduino IDE 才能编译本工程。官方操作说明可参考：

- [PlatformIO IDE for VS Code](https://docs.platformio.org/en/latest/integration/ide/vscode.html)
- [Arduino ESP32 官方文档](https://docs.espressif.com/projects/arduino-esp32/en/latest/)
- [ESP32-S3 USB CDC 烧录说明](https://docs.espressif.com/projects/arduino-esp32/en/latest/tutorials/cdc_dfu_flash.html)

## 4. 硬件准备与安全底线

### 4.1 最小开发组合

第一次上电只准备：

- ESP32-S3-CAM 主板；
- 一根确认可以传数据的 USB 线；
- 稳定的 USB 口或 5 V 电源；
- 电脑上的 VS Code。

先不要连接摄像头和所有传感器。确认主板能识别、能烧录、能输出串口后，再逐项增加外设。

### 4.2 必须遵守

- ESP32-S3 GPIO 不耐 5 V，外设 TX、SDA、SCL 若输出 5 V，必须加电平转换；
- I2C 上拉电阻接 3.3 V，不能上拉到 5 V；
- 蜂鸣器负载通过 MOS 管驱动，不能直接由 GPIO 带大电流；
- 所有模块必须共地；
- 接线和拔插模块前先断电；
- 摄像头和 Wi-Fi 同时工作时电流峰值较大，反复复位首先排查供电和 USB 线；
- 跌倒检测、分级告警和双核 FreeRTOS 当前只保留 TODO 空接口。

## 5. 在 VS Code 中正确打开工程

不要只打开单个 `.ino` 文件，也不要只打开最外层资料目录。应在 VS Code 中选择：

```text
文件 → 打开文件夹 → D:\桌面\拐杖example\代码\SmartCane
```

正确打开后，资源管理器顶层应直接看到：

```text
platformio.ini
SmartCane.ino
src/
```

底部状态栏会出现 PlatformIO 按钮，左侧活动栏会出现蚂蚁图标。首次打开时 PlatformIO 可能需要数十秒建立代码索引。

### 5.1 常用按钮

| 图标/命令 | 作用 | 快捷键 |
|---|---|---|
| `✓` Build | 只编译，不写入开发板 | `Ctrl+Alt+B` |
| `→` Upload | 编译并烧录 | `Ctrl+Alt+U` |
| 插头 Monitor | 打开串口监视器 | `Ctrl+Alt+S` |
| 垃圾桶 Clean | 清理构建缓存 | 无固定键 |
| PlatformIO Home | 管理开发板、库和项目 | 状态栏 Home |

## 6. 认识本工程的入口

Arduino 程序通常由两个函数组成：

```cpp
void setup() {
  // 上电或复位后只执行一次
}

void loop() {
  // setup 完成后不断重复执行
}
```

本工程把真正逻辑放在 `SmartCaneApp` 中：

```cpp
void setup() { app.begin(); }
void loop()  { app.update(); }
```

- `begin()` 初始化串口、I2C、传感器、OLED、Wi-Fi 和摄像头；
- `update()` 快速轮询所有模块，不用长时间等待某一个传感器。

PlatformIO 使用 `src/main.cpp`，Arduino IDE 使用 `SmartCane.ino`。不要删除其中一个，也不要把两者同时加入同一次构建。

## 7. 第一次编译

### 7.1 图形界面方法

1. 确认 VS Code 打开的是 `SmartCane` 文件夹；
2. 查看状态栏环境是否为 `esp32-s3-cam`；
3. 点击 `✓` Build；
4. 第一次需要下载 ESP32-S3 工具链和 Arduino 框架，时间明显长于后续编译；
5. 终端最后出现 `[SUCCESS]` 表示编译通过。

### 7.2 命令行方法

在 PlatformIO 的 Core CLI 终端中执行：

```powershell
pio run -e esp32-s3-cam
```

普通 PowerShell 如果提示找不到 `pio`，应从 PlatformIO 左侧面板打开它自带的终端，或直接使用图形按钮。

### 7.3 如何看编译结果

成功末尾通常包含：

```text
RAM:   [==        ] ...
Flash: [====      ] ...
========================= [SUCCESS] =========================
```

- RAM 是运行时内存，不应长期逼近 100%；
- Flash 是程序存储占用；
- `firmware.bin` 是可烧录固件；
- `firmware.elf` 包含符号，供断点调试和崩溃定位使用。

本工程把产物放在：

```text
%TEMP%\smartcane-platformio-build\esp32-s3-cam\
```

这是为了避开中文路径导致的 ESP32 链接问题，不是文件丢失。

## 8. 连接开发板并识别串口

### 8.1 插入 USB 后检查

在 VS Code 中执行：

```text
PlatformIO → Devices
```

或在 PlatformIO Core CLI 中执行：

```powershell
pio device list
```

Windows 设备管理器的“端口（COM 和 LPT）”中也应出现新设备，常见名称包括：

- Espressif USB JTAG/Serial；
- USB Serial Device；
- CP210x；
- CH340/CH341；
- FTDI。

### 8.2 没有新串口

按顺序排查：

1. 换一根确定支持数据的 USB 线；
2. 换电脑 USB 口，不使用无供电扩展坞；
3. 确认插的是板上正确的 USB/下载接口；
4. 打开设备管理器查看是否有黄色叹号；
5. 若板上使用 CP210x/CH340，安装对应芯片驱动；
6. 按住 BOOT，短按 RST，再观察是否出现下载端口；
7. 断开外围模块，排除外设占用启动脚或造成电源压降。

ESP32-S3 支持原生 USB CDC，但前提是板卡确实把芯片 USB 引脚接到了该 USB 口。当前实测板通过 CH340 暴露 UART0（当前为 COM8），因此本工程定义 `ARDUINO_USB_CDC_ON_BOOT=0`；上位机和串口监视器均连接这个 CH340 端口。

## 9. 烧录固件

### 9.1 正常上传

1. 关闭正在占用端口的其他串口工具；
2. 点击 PlatformIO 的 Upload；
3. 等待终端显示擦除、写入和校验进度；
4. 看到 `[SUCCESS]` 后按一次 RST（若板卡没有自动复位）；
5. 打开 115200 波特率串口监视器。

命令行等价操作：

```powershell
pio run -e esp32-s3-cam -t upload
```

### 9.2 手动进入下载模式

遇到 `Timed out waiting for packet header` 或一直显示 `Connecting...` 时：

1. 按住 BOOT 不松；
2. 短按并松开 RST/EN；
3. 松开 BOOT；
4. 重新选择新出现的端口并点击 Upload；
5. 如果仍失败，可在出现 `Connecting...` 后再按上述顺序操作。

不同厂商板卡的自动下载电路不同，第一次使用原生 USB 时手动进入下载模式是正常现象。

### 9.3 多个串口时固定端口

通常让 PlatformIO 自动识别即可。如果电脑同时连接多个开发板，可在 `platformio.ini` 的环境中临时加入：

```ini
upload_port = COM7
monitor_port = COM7
```

把 `COM7` 替换为实际端口。换 USB 口后 COM 号可能变化，因此不建议把个人端口配置提交给其他人。

## 10. 串口监视与开机自检

### 10.1 打开方式

- 点击底部串口监视图标；
- 或执行：

```powershell
pio device monitor -b 115200
```

`platformio.ini` 已设置 `monitor_speed = 115200`，通常不需要手动指定。

### 10.2 预期日志

复位后重点查看：

```text
[SmartCane] boot
[I2C] devices: ...
[BH1750] online / not found
[Sonar] online / not found at 0x57
[OLED] online / not found
[SmartCane] ready
[State] ...
```

I2C 设备通常为：

| 地址 | 模块 |
|---|---|
| `0x23` 或 `0x5C` | BH1750 |
| `0x3C` | SSD1306 OLED |
| `0x57` | HC-SR04 IIC |

JY901S 和 GPS 使用 UART，不会出现在 I2C 扫描中。

### 10.3 日志乱码

检查两件事：

- 串口波特率必须为 115200；
- VS Code 终端使用 UTF-8。

开机 ROM 日志与应用串口配置可能短暂不同，但应用进入 `[SmartCane] boot` 后应清晰可读。

## 11. 推荐的分阶段硬件调试方法

不要一次接满所有模块后再找问题。每增加一个模块，都应重复“接线 → 上电 → 看日志 → 验证数据”。

### 阶段 1：只测主板

目标：能编译、上传和看到 `[SmartCane] boot`。

允许传感器显示 `not found`，此时只确认主控、USB、Flash 和串口正常。

### 阶段 2：测试 I2C 总线

按顺序连接 OLED、BH1750、超声波：

1. 全部共用 GPIO41 SDA、GPIO42 SCL；
2. 确认 3.3 V 上拉和共地；
3. 每接一个模块，看 I2C 地址是否新增；
4. 如果接入某个模块后全部地址消失，重点检查 SDA/SCL 接反、短路或 5 V 上拉。

### 阶段 3：测试 JY901S

接线方向：

```text
JY901S TX → ESP32 GPIO39（RX）
JY901S RX ← ESP32 GPIO38（TX）
GND       ↔ GND
```

默认 9600 bit/s。网页状态中的 `imu.valid` 应变为 `true`，转动模块时 roll/pitch 应变化。

若始终离线：

- 检查 TX/RX 是否交叉；
- 确认模块没有被上位机改成其他波特率；
- 检查输出是否确实是 `0x55` 开头的维特协议帧；
- 确认电平为 3.3 V。

### 阶段 4：测试 GPS

接线方向：

```text
ATGM336H TX → ESP32 GPIO47（RX）
ATGM336H RX ← ESP32 GPIO21（TX）
GND         ↔ GND
```

在室外开阔位置等待定位。能接收 NMEA 不等于已经定位：

- `online` 含义：最近收到合法 RMC/GGA 语句；
- `valid` 含义：RMC 状态有效或 GGA 定位质量大于 0；
- 室内长期显示未定位通常不是代码错误。

### 阶段 5：测试告警和照明

1. 遮挡并移开超声波，确认距离变化；
2. 检查蜂鸣器和照明 LED 的硬件接口是否通过 MOS 驱动；
3. 当前不执行分级告警、SOS 锁存或自动照明逻辑，相关验证待 TODO 完成后进行。

### 阶段 6：最后连接摄像头

摄像头最容易暴露供电、排线和 PSRAM 问题，因此最后测试：

1. 断电后插紧 OV2640 排线并确认方向；
2. 上电查看是否反复重启；
3. 打开网页 `/capture` 测单张图；
4. 再打开 `:81/stream` 测视频；
5. 图像颠倒时修改 `CAMERA_VFLIP` 或 `CAMERA_HMIRROR`。

## 12. Wi-Fi 和网页调试

### 12.1 热点模式（最容易验证）

保持 `UserConfig.h` 中 `WIFI_SSID` 为空：

1. 手机或电脑连接 `SmartCane-Camera`；
2. 密码为 `12345678`；
3. 浏览器打开 `http://192.168.4.1/`；
4. 页面应显示距离、照度、GPS、IMU 和视频。

### 12.2 路由器模式

在 `UserConfig.h` 填写：

```cpp
constexpr char WIFI_SSID[] = "你的Wi-Fi名称";
constexpr char WIFI_PASSWORD[] = "你的Wi-Fi密码";
```

重新编译和上传后，从 OLED 或串口 `[State]` 行查看 IP。电脑/手机必须与设备处于可互访的同一局域网。

不要把真实密码上传到公开代码仓库。修改前先备份，演示或提交时恢复为空。

### 12.3 单独测试 API

在 PowerShell 中把 IP 替换为设备地址：

```powershell
Invoke-RestMethod http://192.168.4.1/api/status
Invoke-WebRequest -Method Post http://192.168.4.1/api/sos
Invoke-WebRequest -Method Post http://192.168.4.1/api/cancel
Invoke-RestMethod 'http://192.168.4.1/api/light?mode=auto'
```

浏览器可直接测试：

```text
http://192.168.4.1/capture
http://192.168.4.1:81/stream
```

## 13. 零基础 C++/Arduino 阅读要点

### 13.1 `.h` 和 `.cpp`

- `.h` 通常声明“这个模块能做什么”；
- `.cpp` 实现“具体怎么做”；
- 例如 `Bh1750.h` 声明 `readLux()`，`Bh1750.cpp` 负责 I2C 命令和换算。

### 13.2 类和对象

```cpp
Bh1750 lightSensor_(Wire);
```

`Bh1750` 是类，相当于设计图；`lightSensor_` 是对象，相当于按设计图制造出的一个实例；`Wire` 告诉它使用哪条 I2C 总线。

### 13.3 `constexpr`

```cpp
// TODO：后续补充照明和告警参数。
```

表示编译期常量。修改后必须重新编译和上传，设备运行时不会自动变化。

### 13.4 `millis()` 与非阻塞

错误的长阻塞写法：

```cpp
delay(5000); // 这 5 秒里网页、GPS、按键都无法及时处理
```

本工程使用：

```cpp
if (nowMs - lastReadMs >= intervalMs) {
  // 到时间才执行一次
}
```

这种写法让多个任务在一个主循环中并行推进。

### 13.5 `valid` 和更新时间

传感器读数不是永远可信。工程为每类数据保存：

- 数值；
- `valid` 有效标志；
- `updatedAtMs` 最近更新时间。

新增控制逻辑时必须先判断数据有效和是否过期，不能只判断数值。

## 14. 如何安全修改工程

### 14.1 只调参数

修改 `src/config/UserConfig.h`，一次只改一类参数：

- 跌倒、分级告警和照明参数：当前尚未定义，待 TODO 完成后补充；
- 采样速度：`*_INTERVAL_MS`；
- Wi-Fi、热点和图像方向。

修改后执行：编译 → 上传 → 重复原测试 → 记录结果。

### 14.2 改接线

修改 `BoardConfig.h`。先对照原理图确认新 GPIO：

- 没被摄像头占用；
- 不是启动绑带脚，或已正确处理上拉/下拉；
- 支持目标外设；
- RX/TX 方向正确。

### 14.3 新增传感器

推荐流程：

1. 在 `src/drivers/` 新建 `NewSensor.h/.cpp`；
2. 先只实现 `begin()` 和读取函数；
3. 在 `SmartCaneApp.h` 增加对象；
4. 在 `begin()` 初始化；
5. 在 `updateSensors()` 非阻塞读取；
6. 在 `SystemState.h` 增加需要共享的数据；
7. 最后再接入 OLED、告警和网页。

不要先在 `SmartCaneApp.cpp` 里写大量设备协议代码，否则后续很难维护。

### 14.4 修改网页

网页 HTML/CSS/JavaScript 位于 `WifiCameraServer.cpp` 的 `INDEX_HTML` 原始字符串中。修改后需要重新编译和上传，网页不是独立存放在文件系统中的。

## 15. 调试方法：从简单到高级

### 15.1 第一级：编译器报错

双击 VS Code“问题”面板中的错误，先处理最上面的第一条。后续几十条常常是第一条引起的连锁错误。

常见类型：

| 错误关键词 | 含义 |
|---|---|
| `No such file or directory` | 头文件路径或库不存在 |
| `was not declared in this scope` | 名字拼错、缺少声明或作用域不对 |
| `multiple definition of setup/loop` | 两个入口被同时编译 |
| `undefined reference` | 声明了函数但没有实现，或实现未加入构建 |
| `expected ';'` | 前一行或当前行缺少分号/括号 |

### 15.2 第二级：串口日志

这是本工程首选调试方法。新增日志示例：

```cpp
Serial.printf("[Sonar] valid=%d distance=%.1f\n",
              sensors_.distanceValid, sensors_.distanceCm);
```

建议每条日志带模块前缀，如 `[GPS]`、`[IMU]`、`[Camera]`，避免输出无法归属。

不要在高速主循环每次都打印。使用时间间隔，否则串口输出本身会改变系统时序。

### 15.3 第三级：最小化故障

当系统异常时：

1. 断开所有可选外设；
2. 回到最近一次能工作的固件；
3. 每次只恢复一个模块；
4. 每一步记录电压、日志和现象；
5. 区分“编译问题、烧录问题、硬件问题、协议问题、业务逻辑问题”。

### 15.4 第四级：异常解码

若串口出现 Guru Meditation 和回溯地址，可临时在 `platformio.ini` 的环境中加入：

```ini
monitor_filters = esp32_exception_decoder
```

重新打开 PlatformIO 串口监视器后，回溯更容易映射到源文件和行号。排查完成后可保留该过滤器，也可删除。

### 15.5 第五级：断点/JTAG

VS Code 左侧“运行和调试”中已有 PlatformIO 自动生成的 `PIO Debug` 配置。真正断点调试需要：

- 板卡暴露 ESP32-S3 原生 USB-JTAG，或连接兼容 JTAG 调试器；
- 正确的 USB 模式、驱动和调试连接；
- Debug 构建和可用的 `firmware.elf`。

串口能输出不代表 JTAG 一定可用。零基础阶段先掌握日志和最小化测试，再使用断点调试。

## 16. 常见问题速查

| 现象 | 优先原因 | 处理方法 |
|---|---|---|
| VS Code 显示 `failed to fetch` | 代理端口、Clash 模式或当前节点错误 | 确认 Clash 规则模式、7897 端口和 VS Code `http.proxy`，再重启 VS Code |
| PlatformIO 下载开发板/库失败 | Core 没继承代理 | 检查 `HTTP_PROXY/HTTPS_PROXY`，确认 Clash 正常，再重试 |
| 编译找不到头文件 | 工程打开层级错误或索引未生成 | 直接打开 `SmartCane` 文件夹，执行 Build/Rebuild IntelliSense |
| 链接器在中文路径报错 | ESP32 工具链路径兼容性 | 保留当前 `build_dir=${sysenv.TEMP}/...` 配置 |
| 没有 COM 口 | USB 线只供电、驱动缺失、接口错误 | 换数据线/USB 口，查设备管理器，尝试 BOOT+RST |
| `Timed out waiting for packet header` | 没进入下载模式或端口被占用 | 关闭串口工具，手动 BOOT+RST，重新选端口 |
| 上传成功但无日志 | 端口/波特率错误或 USB CDC 模式不匹配 | 选新出现的端口，115200，按 RST；核对原生 USB 与 USB-UART 接口 |
| I2C 显示 `none` | SDA/SCL 接反、未共地、上拉/电压错误 | 断电逐线检查，先只接一个 I2C 模块 |
| 只有某个 I2C 地址缺失 | 设备地址、供电或模块协议不符 | 查模块标签/手册，BH1750 检查 `0x23/0x5C` |
| IMU 始终离线 | TX/RX、波特率或协议错误 | 交叉 RX/TX，核对 9600 和 `0x55` 帧 |
| GPS 有数据但未定位 | 室内无卫星或天线条件差 | 到室外开阔处等待，观察卫星数和定位质量 |
| 距离一直无效 | 超声波版本/协议不同 | 确认是 2021 IIC 版、地址 `0x57`、命令 `0x01` 和 24 位微米数据 |
| 相机初始化失败 | 排线、引脚、供电或 PSRAM 配置 | 断电重插排线，核对板型和 OPI PSRAM，使用稳定 5 V 电源 |
| 相机开启后反复重启 | Brownout 或 PSRAM/Flash 模式不匹配 | 换短 USB 线/强电源，断开大负载，核对 `qio_opi` 配置 |
| 网页能开但无视频 | 相机未就绪或 81 端口不可达 | 先测 `/capture`，再测 `IP:81/stream`，查看供电和相机状态 |
| 网页命令偶尔无响应 | 网络丢包或短时间命令过密 | 等待状态刷新，降低点击频率，检查信号强度 |
| 拐杖靠墙触发跌倒 | 持续倾斜分支的预期限制 | 调大确认时间/角度，或加入握持/压力条件后再启用该分支 |

## 17. 跌倒算法的正确调试方法

不要直接拿设备做危险跌倒实验。建议：

1. 先把 JY901S 固定到与最终产品一致的位置；
2. 记录正常行走、转弯、坐下、放下拐杖、靠墙和乘车数据；
3. 在软垫和有人保护的条件下做模拟跌落；
4. 分析加速度模长、roll、pitch 和时间顺序；
5. 调整阈值后，重新回放所有正常行为；
6. 统计漏报与误报，不要只验证一次成功案例；
7. 最终产品应增加握持、压力或其他上下文信息。

参数意义：

| 参数 | 含义 | 调大后的大致效果 |
|---|---|---|
| `FREE_FALL_G` | 自由落体判定上限 | 更容易进入自由落体状态 |
| `IMPACT_G` | 撞击判定下限 | 更不容易确认撞击 |
| `TILT_ANGLE_DEG` | 倾倒角度 | 更不容易判为倾倒 |
| `IMPACT_WINDOW_MS` | 自由落体后等待撞击窗口 | 接受更晚的撞击 |
| `POST_IMPACT_CONFIRM_MS` | 撞击后姿态确认等待 | 给设备更多稳定时间 |
| `TILT_CONFIRM_MS` | 缓慢倾倒持续时间 | 降低短时倾斜误报 |

## 18. 每次修改后的回归检查

完成任何代码修改后，至少确认：

- [ ] PlatformIO 编译为 `[SUCCESS]`；
- [ ] Flash/RAM 占用没有异常暴涨；
- [ ] 能正常烧录和重启；
- [ ] I2C 地址完整；
- [ ] IMU、GPS 在线状态符合实际；
- [ ] 超声波距离与实际变化一致；
- [ ] 三档障碍告警节奏正确；
- [ ] SOS 能触发，实体按键再次按下和网页均能取消；
- [ ] 自动、手动开灯和关闭都正常；
- [ ] 热点/路由器模式可以访问网页；
- [ ] `/api/status` JSON 合法；
- [ ] 单张抓拍和视频流正常；
- [ ] 连续运行一段时间没有重启、卡死或明显内存异常；
- [ ] 正常放置、靠墙和移动不会产生不可接受的跌倒误报。

## 19. 推荐学习顺序

### 第 1 阶段：能操作

- 会打开正确工程目录；
- 会 Build、Upload、Monitor；
- 会用 BOOT/RST；
- 会读 I2C 地址和 `online/not found`。

### 第 2 阶段：会调参数

- 理解 `UserConfig.h`；
- 修改距离、照度和采样周期；
- 每次修改后做回归测试。

### 第 3 阶段：能读代码

- 理解 `setup()/loop()`；
- 理解 `.h/.cpp`、类、对象和 `constexpr`；
- 理解 `millis()` 非阻塞调度；
- 能从 `SmartCaneApp` 跟踪一条传感器数据流。

### 第 4 阶段：能扩展

- 独立增加一个驱动；
- 把数据加入 `SensorSnapshot`；
- 在 OLED 或网页展示；
- 在控制层增加规则而不破坏驱动层。

### 第 5 阶段：能系统调试

- 会最小化故障；
- 会分析供电、总线、协议和软件状态；
- 会解码异常回溯；
- 有条件时使用 USB-JTAG/JTAG 断点调试。

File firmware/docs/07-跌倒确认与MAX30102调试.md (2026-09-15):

# 跌倒确认与 MAX30102 调试

本版本在不改变现有避障、SOS、照明、GPS、相机和网页控制接口的前提下，增加了：

- `SUSPECTED_FALL`（疑似跌倒）4 秒确认状态；
- MAX30102 原始 RED/IR PPG 采样、手指检测、心率、血氧估算与信号质量；
- 网页、`/api/status` JSON、串口状态行中的新增状态。

> 心率与血氧仅用于课程项目的非医疗监测演示，不能作为医疗诊断或医疗级测量结果。

## 1. 跌倒确认流程

```text
现有 IMU 跌倒规则命中
  -> SUSPECTED_FALL（短促蜂鸣、LED 快闪）
  -> 等待 4 秒
     -> 期间按实体 SOS 键或网页“解除告警”：回到 NORMAL
     -> 未取消：转为锁存 FALL，沿用原有持续报警/相机事件行为
```

`SUSPECTED_FALL` 不会使用 `delay()` 阻塞系统，摄像头、GPS、避障和 Wi-Fi 会继续运行。
取消后，跌倒检测有 3 秒冷却时间，避免同一次动作立即重复触发。

### 测试

1. 上传固件，打开串口监视器（115200）。
2. 在软垫或安全环境下对拐杖进行受控倾倒测试；不要让人实际跌倒。
3. 出现 `SUSPECTED_FALL` 后，在 4 秒内按一次实体按键或网页“解除告警”，应回到正常。
4. 再次测试且不取消，约 4 秒后应显示 `FALL`，并保持原有蜂鸣器/LED 告警。
5. 在 `FALL` 下再次按实体按键或网页解除，应解除告警。

确认等待时间在 `src/config/UserConfig.h` 的
`SUSPECTED_FALL_CONFIRM_MS` 中设置，默认 `4000` ms。

### 高频标定数据

正式阈值标定不要使用 5 Hz `SC1 TEL` 峰值。Qt 上位机的高频采集区会按实际收到的
每个新 JY901S 样本保存 CSV，记录原始九轴、A/G/Tilt、候选阶段和告警结果。
每次先记录 5 秒直立基线，点击“动作开始”，完成动作后再保留 5 秒尾段。

采集目录中的 `trials.csv` 自动将模拟跌倒分为 TP/FN、正常动作分为 FP/TN，并显示：

```text
召回率 = TP / (TP + FN)
误报率 = FP / (FP + TN)
```

正常动作进入 `SUSPECTED_FALL` 即计为误报。必须分开标定集和验证集，只有独立
验证数据稳定后才能冻结 `UserConfig.h` 中的跌倒阈值。

## 2. MAX30102 接线

MAX30102 与现有 I2C 超声波都使用地址 `0x57`，不能接到现有 GPIO41/42 总线。
本工程将 MAX30102 放在第二路 I2C：

| MAX30102 模块 | ESP32-S3-CAM | 说明 |
|---|---:|---|
| VCC / VIN | 3V3 | 仅在模块明确支持 3.3 V 供电时这样连接；不要把裸芯片直接接到 3.3 V。 |
| GND | GND | 必须共地。 |
| SDA | GPIO2（板上 G2） | 第二路 I2C 数据线。 |
| SCL | GPIO48（板上 G48） | 第二路 I2C 时钟线。GPIO48 的板载 RGB 不再单独使用。 |
| INT | 不接 | 当前采用 FIFO 轮询，不需要中断线。 |

不要把 MAX30102 的 SDA/SCL 接到现有 GPIO41/42；那会与 `0x57` 超声波冲突。
MAX30102 模块的 I2C 上拉必须是 3.3 V 电平。

## 3. MAX30102 上电测试

上传后，串口启动日志应出现：

```text
[MAX30102] online on I2C1 SDA=2 SCL=48
```

若没有接模块，会出现 `not found`，随后每 5 秒重试一次；这不会影响其他已实现功能。

正常状态行示例：

```text
[State] NORMAL ... max30102=ok finger=yes hr=76.0 spo2=98.0 sq=0.82 ...
```

网页会增加三张卡片：心率、血氧、PPG。

- `模块离线`：检查 VCC、GND、GPIO2/GPIO48、SDA/SCL 是否接反。
- `请放置手指`：模块在线，但 IR 值未达到手指接触初始阈值。
- `信号采集`：已检测到手指，但仍在积累约 4 秒波形或质量不足。
- 显示百分比：表示信号质量；绿色时才同时显示心率和血氧估算值。

测试时用手指轻压传感器，保持不动至少 8～12 秒，并避免强环境光直射。走路、松动、手指过冷或模块光学结构不佳都会使读数无效。

## 4. 初始参数位置

均在 `src/config/UserConfig.h`：

- `MAX30102_FINGER_IR_THRESHOLD`：手指存在阈值，默认 `50000`；若始终显示“请放置手指”，可根据串口 raw IR 数据适当降低。
- `MAX30102_LED_CURRENT`：RED/IR LED 初始驱动电流。
- `MAX30102_VALID_QUALITY_MIN`：网页允许显示正式估算值的最低信号质量。
- `MAX30102_SPO2_WINDOW_MS`：血氧计算窗口，默认 4 秒。

建议一次只改一个参数，上传后记录稳定静止数据，再决定是否保留修改。

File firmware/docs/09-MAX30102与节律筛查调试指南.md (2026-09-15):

# MAX30102 与节律筛查调试指南

## 1. 当前实现与本轮目标

当前固件已经具备 MAX30102 RED/IR FIFO 读取、手指检测、基础滤波、峰值检测、HR、
课堂演示级 SpO₂ 估算、SQI、15 秒 IBI/HRV 特征窗口和 6 特征 INT8 基线分类器。
本轮调试要把“能显示数值”推进到“原始数据可追溯、算法可验证、误差可量化”。

必须明确两个边界：

1. 当前 SpO₂ 公式 `110 - 25R` 是课堂/原型近似，不是成熟医疗算法；
2. 当前节律权重是集成基线，`model_calibrated=false`，没有经过 ECG 标注公开数据训练，不能声称能诊断房颤。

## 2. 本次已经补充的调试能力

### 2.1 固件串口协议

新增命令：

```text
SC1 CMD PPG STREAM ON
SC1 CMD PPG STREAM OFF
```

新增数据帧：

```text
SC1 PPG HEADER seq,t_ms,red,ir,red_dc,ir_dc,red_ac,ir_ac,filtered_ir,envelope,peak_candidate,beat_accepted,ibi_ms,finger,sqi,hr_bpm,spo2_pct,valid,fifo_overflow
SC1 PPG <对应 CSV 数据>
```

IMU 与 PPG 高频流会自动互斥。普通 5 Hz JSON 遥测继续运行，用于补充节律窗口、
IMU 运动量、推理耗时和模型内存字段。

### 2.2 Qt 页面

新增“MAX30102 · PPG/血氧数据采集”区域，支持：

- 试验编号和场景标签；
- 开始、动作/放指标记、停止并保存；
- 25 Hz 实际采样率、序号丢帧、最大间隔、FIFO 溢出；
- 手指覆盖率、有效率、平均 SQI、ADC 削顶率；
- RED/IR AC、滤波 IR、接受峰和 SQI 实时曲线；
- CSV 自动保存及试验索引；

## 3. 先确认硬件事实

### 3.1 I²C 总线

目标描述写的是“第二路 I²C”，但当前实机配置为：

```cpp
MAX30102_USE_PRIMARY_I2C = true
```

也就是 MAX30102 当前仍在主 I²C GPIO41/42 上。可先按现状完成算法调试；如果后续
启用同为 `0x57` 的超声模块，必须将两个器件分到不同总线或使用 I²C 多路复用器，
否则地址冲突。不要在硬件尚未改线时直接把配置改成第二路。

### 3.2 真实采样率

MAX30102 ADC 设置为 100 samples/s，FIFO 配置 `SMP_AVE=4`。官方手册说明硬件会
对相邻样本平均并抽取，因此每个 FIFO RED/IR 对应 4 个 ADC 转换，实际输出为：

```text
100 / 4 = 25 Hz
每个 FIFO 样本间隔约 40 ms
```

固件现在按 25 Hz 重建 FIFO 批量读取的时间戳。调试时以 Qt 显示的真实频率为准。
官方依据：[MAX30102 Data Sheet](https://www.analog.com/media/en/technical-documentation/data-sheets/MAX30102.pdf)。

## 4. 第一步：链路与 FIFO 验收

先选“无手指空载”，记录 15 秒；再选“稳定覆盖·静止”，记录 60 秒。

检查：

| 指标 | 建议通过条件 |
|---|---|
| 实际采样率 | 24～26 Hz |
| 样本间隔中位数 | 约 40 ms |
| 序号丢帧 | 0；长记录允许低于 0.5% |
| 最大间隔 | 通常不超过 120 ms |
| FIFO overflow | 必须为 0 |
| 无手指状态 | `finger=false`，HR/SpO₂ 不输出有效值 |
| 稳定覆盖 | 原始值不长期接近 262143，削顶率应接近 0 |

如果 overflow 增加或频率明显低于 25 Hz，先检查 I²C、SensorTask 阻塞和串口带宽，
不要先调 HR/SpO₂ 公式。

## 5. 第二步：原始 PPG 与滤波验证

依次采集以下场景，每类先做 1 次确认流程，再做 3～5 次：

| 场景 | 单次时长 | 主要用途 |
|---|---:|---|
| 无手指空载 | 15 s | 背景、手指阈值、误触发 |
| 稳定覆盖·静止 | 60 s | 波形、峰值、IBI、HR/SpO₂ |
| 重复放置/移开 | 6 次 | 手指检测响应与状态复位 |
| 轻压 / 正常压 / 重压 | 各 30 s | 接触压力、DC、AC、削顶影响 |
| 手指轻微移动 | 30 s | 局部运动伪影 |
| 拐杖轻微晃动 | 30 s | IMU 运动抑制与节律状态 |
| 强环境光 | 30 s | 环境光鲁棒性 |
| 运动后恢复 | 90 s | 心率变化跟踪能力 |

每次统一流程：

1. 连接 TTL，确认 MAX30102 显示在线；
2. 选择场景，填写唯一编号；
3. 点击“开始记录”，先留 5 秒基线；
4. 点击“动作/放指开始”；
5. 完成场景并保持到规定时长；
6. 点击“停止并保存”；
7. 检查采样率、丢帧、overflow、手指率、有效率、SQI 和削顶率；
8. 异常试验写入备注，不要删除后假装未发生。

曲线应重点观察：

- RED 与 IR AC 是否具有同周期脉搏形态；
- 滤波 IR 是否保留主峰，同时减少基线漂移和高频毛刺；
- 白色峰线是否与肉眼主峰一一对应；
- 移动时是否出现大幅伪影，SQI 是否下降；
- 轻压时信号是否过弱、重压时是否削顶或 AC 反而下降。

## 6. 第三步：手指检测、SQI 和有效率

从 `no_finger` 与 `finger_reposition` CSV 统计：

```text
手指检测灵敏度 = 正确识别有手指的样本 / 实际有手指样本
无手指特异度 = 正确识别无手指的样本 / 实际无手指样本
放指响应时间 = ACTION_START 到 finger=true 的时间
移开响应时间 = 实际移开到 finger=false 的时间
有效率 = valid=true 样本 / 有手指样本
```

当前手指阈值为 IR `50000`。只有无手指与不同压力数据都收齐后才考虑调整；不要只用
一根手指的一次记录定阈值。

## 7. HR/SpO₂ 精度对照：本阶段暂缓

当前没有标准参考仪器，本阶段不设置参考对照组，Qt 也不提供参考 HR/SpO₂ 输入及
MAE 统计。现有数据只用于验证 PPG 波形、有效率、趋势和算法链路，不能据此声称 HR
或 SpO₂ 测量精度已经完成校准。以后具备参考仪器时，再单独恢复同步对照流程。

禁止通过憋气、遮挡呼吸或其他危险方式人为制造低血氧。当前 SpO₂ 公式仍然只是课程
原型基线，不能作为医疗诊断依据。

## 9. 第六步：节律筛查本机验证

本机采集不能可靠产生房颤真实标签，因此主要验证数据链和误报抑制：

1. “节律稳定窗口”静止 60 秒 × 10 次；
2. “手指轻微移动”30 秒 × 5 次；
3. “拐杖轻微晃动”30 秒 × 5 次；
4. 检查前 15 秒状态为 `COLLECTING`；
5. 运动时应进入 `MOTION_ARTIFACT`，不能输出高置信异常；
6. 稳定窗口记录 IBI mean、SDNN、RMSSD、pNN50、beat count、分类、置信度；
7. 统计正常静止误报次数、运动伪影抑制率、有效窗口率和连续运行假告警次数。

本机正常数据的目标是证明“不会乱报”和“特征实现一致”，不是证明能识别房颤。

## 10. 第七步：公开数据训练

选择带 ECG 参考标签的公开 PPG 节律数据，而不是仅有普通运动 PPG 的数据集。处理时：

1. 按受试者划分训练、验证、测试集，禁止同一人的窗口同时进入训练和测试；
2. 将公开 PPG 的峰值/IBI 提取流程与固件保持一致，或明确记录差异；
3. 以 15 秒窗口计算当前 6 个输入：IBI CV、RMSSD/mean IBI、pNN50、最大相邻 IBI 差/mean、SQI、心率越界分数；
4. 先训练可解释的逻辑回归/线性分类器，再考虑小型 MLP；
5. 完成 INT8 量化，导出权重并替换 `RhythmClassifier.cpp` 中的基线常量；
6. 只有独立测试集通过后，才把 `RHYTHM_MODEL_CALIBRATED` 改为 `true`。

必须报告：

- 三分类混淆矩阵；
- 每类 precision、recall/sensitivity、specificity、F1；
- macro-F1、balanced accuracy，条件允许时给 AUROC；
- 受试者数量、窗口数量、无效窗口比例；
- 连续窗口确认前后的召回率与误报率；
- 每小时假告警数。

## 11. 端侧性能记录

固件遥测与 PPG CSV 已补充：

- `rhythm_inference_us`：最近一次 6 特征模型推理耗时；
- `rhythm_inference_count`：累计推理次数；
- `rhythm_model_bytes`：权重和偏置常量字节数；
- `rhythm_classifier_state_bytes`：分类器状态对象字节数。

本次构建结果：

```text
RAM  : 55300 / 327680 bytes（16.9%）
Flash: 1012305 / 1966080 bytes（51.5%）
```

烧录后至少记录 30 次推理的 `inference_us`，报告中给平均值、P95 和最大值。训练后的
模型替换基线模型时，应重新记录同样指标并比较 RAM、Flash 和推理耗时增量。

## 12. 最终交付应包含

- 各场景原始 PPG CSV 和 `trials.csv`；
- RED/IR 原始与滤波波形图、峰值和 SQI 图；
- 手指检测响应与混淆统计；
- HR/SpO₂ 趋势、有效率及“未进行标准仪器精度对照”的局限说明；
- 公开数据来源、受试者划分、训练脚本和模型文件；
- 节律混淆矩阵和分类指标；
- 端侧 RAM、Flash、模型字节数、推理平均/P95/最大耗时；
- 明确的非医疗诊断声明。

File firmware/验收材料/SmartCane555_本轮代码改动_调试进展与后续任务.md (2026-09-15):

# SmartCane555 本轮代码改动、调试进展与后续任务

> 基准版本：`SmartCane555.zip`  
> 当前依据：本轮 `验收材料.zip` + 已完成的实机调试记录  
> 目标：记录相对于 555 基准版已经做了什么、哪些已经可以结束，以及后续真正还需要做什么。

---

# 一、当前总体结论

相对于 `SmartCane555.zip`，本轮工作已经不是简单的“把新增模块接上”，而是完成了三类工作：

1. **跌倒检测从初始组合阈值方案发展成经过数据标定和独立验收的双路径检测方案；**
2. **MAX30102 从基础 HR/SpO₂ 原型链进一步完成了高频采集、峰值算法修正、IBI/HRV、SQI、节律窗口以及端侧推理性能验证；**
3. **公网 MQTT 固件与 Broker 链路已经过实机验证，并已把远程监护网页部署到阿里云 ECS。**

按当前课程项目/展示目标来看：

- **IMU 跌倒检测：已经完成，可停止继续调参；**
- **MAX30102 基础测量与信号处理：已经完成课程原型级调试；**
- **公网基础设施：ECS、Docker、Nginx、公网 IP 登录和演示数据页面已经完成；**
- **公网真实数据：历史记录已证明 ESP32 能通过 TLS 向 EMQX 发布数据，但仍需在拐杖在场时做一次“ESP32 → EMQX → ECS → 手机 4G/5G”的短程闭环复测并留图；**
- **目前唯一明显还未完成的核心算法开发，是把节律筛查的 baseline 权重替换为真正用有标签公开数据训练、验证得到的模型。**

标准血氧仪对照当前明确暂缓；网络也不按生产级系统继续做 LWT、8～24 h 长稳等深度可靠性验收。域名和 HTTPS 是推荐的安全升级，但不是本课程公网 IP 演示的硬性前置条件。

> 2026-09-02 部署更新：公网网页当前以 `SMARTCANE_DEMO=true` 运行，因此“公网服务器可访问”已经验收，“真实拐杖完整端到端数据”不能仅凭演示模式判定完成。

## 完成度复核表

| 模块/要求 | 状态 | 复核结论 |
|---|---|---|
| FreeRTOS 多任务与双核调度 | 已完成 | 传感器/决策/执行器与网络/遥测已分核运行 |
| 跌倒检测优化 | 已完成（课程原型） | 双路径检测、4 s 二次确认、取消冷却、独立样本验收均已留存 |
| 避障、SOS、照明和状态机 | 已完成 | 原有功能保留；当前 MAX30102 台架因 `0x57` 地址冲突暂时停用 I2C 超声波 |
| MAX30102 心率/血氧与 PPG 质量 | 已完成（课程原型） | 采样、峰值、IBI、HRV、SQI 和性能统计已验证；不宣称医疗精度 |
| TinyML 端侧推理链 | 基础链已完成 | 特征、量化、推理和状态机可运行 |
| 有标签异常节律训练模型 | 未完成 | 当前仍是 baseline 权重，`model_calibrated=false` |
| MQTT TLS 五类 Topic 发布 | 已完成 | presence、telemetry、vitals、gps、event 已实现并有 Broker/MQTTX 验收记录 |
| 独立公网前后端、SSE、只读页面 | 已完成 | 前端已拆分；浏览器不保存 MQTT 凭据；远程控制关闭；摄像头标注近场访问 |
| ECS Docker、Nginx、公网 IP 登录 | 已完成 | 演示模式健康检查和公网登录已通过 |
| 域名与 HTTPS | 未做、当前可选 | 公网 IP 演示不依赖域名；若长期真实使用则应补 HTTPS |
| 最终实机到手机移动网络闭环 | 未完成 | 等拐杖在场后关闭 Demo，做一次短回归并留证 |
| 公布源码前凭据清理 | 未完成 | 必须移除/轮换工程与服务器中的真实账号、密码和 Key |

---

# 二、相对于 SmartCane555.zip 的主要代码改动

## 1. 跌倒检测：从单一路径规则改为双路径状态机

主要修改文件：

```text
src/control/FallDetector.cpp
src/control/FallDetector.h
src/config/UserConfig.h
src/app/SmartCaneApp.cpp
src/services/SerialTelemetry.cpp/.h
```

### 1.1 FallDetector 算法结构修改

555 基准版主要逻辑为：

```text
低重力 / 冲击
→ 候选
→ 冲击已出现
→ 倾斜 + 低角速度保持
→ FALL candidate
```

本轮修改成两条并行确认路径：

```text
路径 A：严格路径
低重力/冲击
→ 必须观察到 impact
→ 大倾角 + 静止
→ 连续保持 600 ms
→ 检出

路径 B：深度失重路径
深度低重力 ≤ 0.40 g
→ 即使 10 Hz IMU 未采到冲击峰值
→ 大倾角 + 静止
→ 连续保持 1200 ms
→ 检出
```

主要新增：

- `deepFreeFallSeen_`；
- `StrictHolding / DeepHolding / BothHolding` 等候选阶段；
- strict/deep 两套独立保持计时；
- `Diagnostics` 调试结构；
- `phaseName()`；
- 加速度模长、角速度模长、倾角、free-fall、impact、tilted-and-still 等实时诊断量。

这次修改解决的核心问题是：**JY901S 实际约 10 Hz 时可能漏掉非常短的冲击峰值，因此不能把“必须采到 impact”作为所有跌倒的唯一入口。**

### 1.2 跌倒参数重新标定并冻结

555 初始值：

```text
FALL_FREE_FALL_G       = 0.55 g
FALL_IMPACT_G          = 2.20 g
FALL_TILT_DEG          = 55°
FALL_STILL_GYRO_DPS    = 35°/s
FALL_SEQUENCE_WINDOW   = 1500 ms
FALL_TILT_HOLD         = 800 ms
```

最终冻结为：

```text
FALL_FREE_FALL_G           = 0.55 g
FALL_DEEP_FREE_FALL_G      = 0.40 g
FALL_IMPACT_G              = 2.20 g
FALL_TILT_DEG              = 55°
FALL_STILL_GYRO_DPS        = 45°/s
FALL_SEQUENCE_WINDOW_MS    = 2000 ms
FALL_TILT_HOLD_MS          = 600 ms
FALL_DEEP_TILT_HOLD_MS     = 1200 ms
SUSPECTED_FALL_CONFIRM_MS  = 4000 ms
FALL_CANCEL_COOLDOWN_MS    = 3000 ms
```

同时增加 `static_assert` 对阈值和时间窗口关系进行编译期检查。

### 1.3 增加 IMU 高频调试数据链

新增串口命令：

```text
IMU STREAM ON
IMU STREAM OFF
```

新增独立 `imuDebugQueue_`，按 JY901S 新样本输出紧凑 CSV，而不是依赖普通 5 Hz JSON 遥测。

记录内容包括：

```text
ax ay az
gx gy gz
roll pitch yaw
A G Tilt
fall phase
free_fall
impact
tilted_still
alarm
suspected_fall
fall_latched
```

这样才能对阈值进行真实数据标定、离线重放和误报/漏报分析。

---

## 2. MAX30102：修正有效采样率并增强数据可观测性

主要修改文件：

```text
src/drivers/Max30102.cpp/.h
src/control/VitalsProcessor.cpp/.h
src/control/RhythmClassifier.cpp
src/model/SystemState.h
src/app/SmartCaneApp.cpp/.h
src/services/SerialTelemetry.cpp/.h
src/config/UserConfig.h
```

### 2.1 修正 FIFO 有效输出率的时间基准

MAX30102 仍使用：

```text
ADC sample rate = 100 Hz
FIFO averaging  = 4 samples
FIFO_CONFIG      = 0x5F
```

但本轮明确加入：

```cpp
FIFO_AVERAGE_SAMPLES = 4;
```

因此：

```text
有效 FIFO 输出率 = 100 / 4 = 25 Hz
实际样本周期 ≈ 40 ms
```

`SmartCaneApp.cpp` 不再按 100 Hz 给 FIFO 数据重建时间戳，而是按 **25 Hz** 处理。

这修复了之前最关键的时间轴问题：否则 IBI 会被压缩约 4 倍，HR 和节律特征都会失真。

同时增加：

- FIFO overflow 读取与记录；
- `lastOverflow()`；
- 采样序号、丢帧、最大间隔等上位机统计依据。

### 2.2 当前实物总线配置调整

当前实物调试配置中：

```text
MAX30102 → 主 I2C GPIO41/42
SONAR    → 暂时关闭
OLED     → 当前 bench 配置关闭
```

原因是 MAX30102 与原超声波模块地址均为：

```text
0x57
```

因此本轮代码增加：

```text
MAX30102_USE_PRIMARY_I2C
SONAR_ENABLED
OLED_ENABLED
```

以及 0x57 地址冲突的编译期保护。

这属于**当前实物接线条件下的 bench 配置**，不是最终硬件拓扑的永久结论。以后如果同时恢复 MAX30102 与 0x57 超声波，需要分离 I2C 总线或增加 I2C 多路复用器。

---

## 3. PPG / HR 算法：针对误峰、短 IBI 和陈旧 HR 做了重点修正

`VitalsProcessor.cpp` 是本轮 MAX30102 部分改动最大的文件。

555 基准版已经包含基础：

```text
去 DC
简单滤波
局部峰值检测
IBI
HR
SpO₂ 原型估算
SQI
HRV 特征
```

本轮在实测数据基础上增加了以下机制。

### 3.1 峰值突出度判据

峰值不再只看：

```text
局部极大值 + 幅度阈值
```

还必须满足相对前一谷值的 **prominence（突出度）**。

目标：减少一个真实心搏内部的小波峰被误认为第二个心搏，从而产生异常短 IBI。

### 3.2 自适应不应期

根据近期 IBI 的稳定情况设置有上限的不应期，抑制明显过早的二次峰。

但同时保留“突出度足够强的提前心搏”进入，避免为了去噪而把真实不规则心搏全部机械删掉。

### 3.3 HR 改用 IBI 中位数

显示 HR 从近期 IBI 均值改为：

```text
HR = 60000 / median(IBI)
```

提高对单个异常间隔的鲁棒性。

注意：**节律特征仍使用未被中位数平滑替代的有效 IBI 序列**，避免 HR 显示平滑反过来破坏节律分析。

### 3.4 长间隔重置旧 IBI 窗口

如果相邻峰之间出现过长间隔：

```text
旧 HR / IBI 连续窗口失效
→ 当前峰只作为新的时间锚点
→ 重新积累连续心搏
```

避免把“手指移开后又重新放上”等不连续数据拼成一个节律窗口。

### 3.5 心搏新鲜度保护

连续约 3 s 没有新的有效心搏时：

```text
旧 HR → NAN / invalid
```

而不是继续把几秒前的 HR 当作当前有效值显示。

这也是最终 P043 有效率下降但仍保留为有效验收样本的原因：系统选择安全失效，而不是输出陈旧数据。

### 3.6 增加 PPG 调试观测量

新增 `PpgProcessingDebug`：

```text
red_dc / ir_dc
red_ac / ir_ac
filtered_ir
envelope
peak_candidate
beat_accepted
ibi_ms
```

并增加：

```text
PPG STREAM ON
PPG STREAM OFF
```

配合独立 `ppgDebugQueue_` 输出 25 Hz CSV。

IMU 高频流与 PPG 高频流设置为互斥，避免串口带宽被同时占满。

---

## 4. 节律筛查：补充端侧性能观测，但模型本身仍是 baseline

当前模型结构仍为 6 维特征的轻量 INT8 线性分类器：

```text
IBI CV
RMSSD / mean IBI
pNN50
max adjacent IBI diff / mean
SQI
HR out-of-range score
```

输出：

```text
NORMAL
IRREGULAR
SUSPECTED_AF
```

本轮新增的主要代码不是“重新训练了模型”，而是增加工程观测量：

```text
inference_us
inference_count
model_bytes
classifier_state_bytes
```

同时把权重/偏置集中为明确的：

```text
MODEL_WEIGHTS
MODEL_BIAS
```

方便后续训练完成后直接替换。

当前仍保持：

```text
RHYTHM_MODEL_CALIBRATED = false
```

这一点必须保留，直到真正用 ECG 标签公开数据完成独立训练和测试。

---

## 5. Qt 上位机与离线分析工具：本轮新增了完整调试链

相对于 555 基准版，本轮围绕两个新任务补充了大量上位机/分析代码。

### IMU 部分

新增/扩展：

```text
串口协议解析
IMU 高频 CSV 采集
实时 IMU 曲线
场景与真实标签记录
trials.csv 汇总
跌倒状态机离线重放
参数网格扫描
自动测试
```

### MAX30102 部分

新增/扩展：

```text
PPG 25 Hz CSV 采集
RED/IR 与滤波波形
峰值标记
IBI
SQI
HR / SpO₂
节律状态
采样率 / 丢帧 / overflow 统计
自动测试
```

这些工具的价值不是最终产品功能，而是让“阈值和算法经过数据验证”能够留下完整证据。

---

## 6. MQTT：固件主体不是本轮新增，主要完成实机验收和远程展示

这里需要和其他两项区分开。

`SmartCane555.zip` 中已经存在：

```text
MqttRemoteService.cpp/.h
MQTT TLS
telemetry/vitals/gps/event
SOS/FALL 等事件接口
```

本轮验收包中的 `MqttRemoteService` 与 555 基准版主体没有实质性代码变化。

本轮真正完成的是：

- 配置并打通公网 MQTT Broker；
- MQTT over TLS / 8883 实机连接；
- 周期 telemetry / vitals / gps 接收；
- SOS QoS 1 事件实测；
- 新增只读远程监护网页；
- 网页显示设备状态、HR、SpO₂、GPS、SOS 等；
- 阿里云 ECS 上的 Docker 服务、Nginx 反向代理、公网 IP 登录和演示模式页面已经打通。

历史 MQTT 验收材料证明了设备可以把真实数据发到公网 Broker；本次 ECS 部署验收则证明了网页能从公网访问。但现有材料没有留下足够证据证明“最终固件真实数据已经从 ESP32 经过 EMQX 到达这台 ECS，并由手机 4G/5G 页面显示”。因此后续只需补一次短程闭环复测，不需要做生产级长稳或重复多轮深度网络测试。

---

# 三、本轮已经完成的调试与验收

## 1. IMU 跌倒检测：已完成

共完成四轮数据采集与调参。

最终冻结参数后的独立验收有效集：

```text
正常动作：12 次
误报：0 次

四方向模拟跌倒：4 次
检出：4 次

TP = 4
FN = 0
FP = 0
TN = 12
```

受控场景下：

```text
召回率 = 100%
误报率 = 0%
```

正常场景覆盖：

```text
静止直立
正常行走
快速行走
大幅摆杖
左转 / 右转
上台阶 / 下台阶
靠墙
正常放下
正常拿起
杖尖碰撞
```

跌倒覆盖：

```text
前 / 后 / 左 / 右
```

并完成：

```text
SUSPECTED_FALL
→ 约 4 s
→ FALL 锁存
```

前三轮 48 条数据和第 4 轮有效数据都进行了离线重放；最终分析工具中累计 64 条有效记录。

**结论：IMU 跌倒检测已经达到课程设计/工程原型交付标准。后续不建议继续调阈值。**

---

## 2. MAX30102 / PPG：基础链路和本地算法调试已完成

总计保存：

```text
43 份 PPG 原始记录
59098 个样本
总时长 2365.49 s ≈ 39.42 min
```

全部数据链：

```text
有效 FIFO 输出率 = 25 Hz
序号丢帧 = 0
FIFO overflow = 0
最大样本间隔 = 50 ms
```

覆盖场景包括：

```text
无手指
稳定覆盖
重复放置 / 移开
轻压 / 正常按压 / 重压
手指或模块运动
环境光变化
运动后恢复
节律稳定窗口
```

最终峰值算法修改后采集 P041～P043：

```text
有效 IBI = 243 个
IBI < 500 ms = 0
IBI > 1200 ms = 0
IBI CV = 0.070 / 0.058 / 0.100
```

说明之前最明显的短 IBI / 双峰问题已经解决。

当前能够完成：

```text
RED / IR 原始采集
去 DC
滤波
峰值检测
IBI
HR 趋势
SpO₂ 原型估算
SQI / valid 门控
15 s 节律窗口
端侧基线推理
```

**本阶段不做标准血氧仪对照。**

原因不是“已经证明 HR/SpO₂ 很准”，而是当前没有合适的可信参考仪器，因此课程项目只保留以下结论：

> 系统能够稳定获取 PPG、完成信号处理、输出 HR/SpO₂ 原型估算，并通过 SQI/valid 对低质量数据进行一定程度拒绝；不报告医疗级绝对精度。

当前 `SpO₂ = 110 - 25R` 仍属于课程原型近似。若课程要求仅为生命体征展示，可以保持现状；无需为了没有可靠 reference 的精度指标继续投入大量时间。

---

## 3. 节律端侧工程链：已完成，模型校准尚未完成

最终三组稳定数据共形成：

```text
29 次端侧推理
29 次 NORMAL
IRREGULAR = 0
SUSPECTED_AF = 0
```

推理性能：

```text
平均 ≈ 65.6 μs
P95   ≈ 95.4 μs
最大  ≈ 106 μs
```

说明：

```text
PPG
→ IBI/HRV 特征
→ 量化特征
→ 端侧分类器
→ 状态机
```

这条工程链已经工作正常，而且 ESP32-S3 的计算开销非常小。

但目前权重仍是 integration baseline，没有经过同步 ECG 标签训练，因此：

```text
model_calibrated = false
```

这是当前项目最主要的未完成项。

---

## 4. MQTT 公网链路：基础链路与公网网页已完成，真实整链待短回归

已经完成：

```text
MQTT over TLS / 8883
Broker 公网连接
周期 telemetry / vitals / gps
SOS QoS 1 事件
只读远程监护网页
阿里云 ECS Docker 健康检查
Nginx 反向代理
公网 IP 登录和演示数据页面
```

当前应准确表述为：

> 系统已实现基于 MQTT TLS 的设备公网遥测，并已把只读监护网页部署到阿里云 ECS；服务器公网访问已完成，最终还需在实机在场时进行一次手机移动网络端到端复测。

本次部署现状：

| 检查项 | 当前状态 | 说明 |
|---|---|---|
| Docker dashboard 服务 | 已完成 | 容器 healthy，后端只绑定 `127.0.0.1:8080` |
| `/livez`、`/readyz` | 已完成 | 演示模式返回 HTTP 200 |
| Nginx 80 端口反向代理 | 已完成 | ECS 本机通过 Nginx 访问返回 HTTP 200 |
| ECS 安全组与公网登录 | 已完成 | 实例关联安全组后，可通过公网 IP 登录 |
| MQTT 只读账号与五个精确 Topic ACL | 已配置 | 建议补一张允许订阅、拒绝越权的控制台或 MQTTX 截图 |
| 域名与 HTTPS | 暂缓/可选 | 公网 IP 课程演示可用；HTTP 登录口令未加密，不适合长期真实使用 |
| 真实拐杖数据进入 ECS 页面 | 待短回归 | 当前服务器为 `SMARTCANE_DEMO=true`，不能用模拟数据替代此项 |
| 手机关闭 Wi-Fi 后查看真实状态 | 待短回归 | 与上一项一次完成并截图留证 |

相关部署边界和验收步骤见 `remote_dashboard/公网IP部署验收记录.md`。

当前**不再要求**进一步完成：

```text
LWT offline 专项测试
Topic ACL 拒绝测试
8～24 h 长稳测试
生产级断网恢复时间评测
公网高可用性设计
```

这些属于产品化网络可靠性，不是当前展示需求的主要矛盾。但上表中的一次真实端到端短回归仍然需要完成。

---

# 四、后续真正还需要做的任务

## 任务 A：完成真正的异常节律模型训练【当前最重要】

类型：**电脑端代码 / 数据处理为主，硬件依赖很小。**

当前硬件端、特征端、部署接口都已经准备好，因此接下来不应继续修改 PPG 底层，而应直接进入模型训练。

建议保持现有 6 维特征接口：

```text
IBI CV
RMSSD / mean IBI
pNN50
max adjacent diff / mean IBI
SQI
HR out-of-range score
```

训练流程：

```text
带同步 ECG 标签的公开 PPG 数据
        ↓
实现与 ESP32 一致的峰值/IBI处理
        ↓
Python 与 ESP32 特征一致性检查
        ↓
按 15 s 窗口生成六维特征
        ↓
按受试者划分 train / val / test
        ↓
先训练逻辑回归/线性模型
必要时再比较小型 MLP
        ↓
独立测试集评估
        ↓
INT8 量化
        ↓
导出权重和偏置
        ↓
替换 RhythmClassifier.cpp
        ↓
RHYTHM_MODEL_CALIBRATED = true
```

最低应记录：

```text
受试者数
窗口数
混淆矩阵
precision
recall / sensitivity
specificity
F1
macro-F1 / balanced accuracy
INT8 前后性能
```

注意：本地 P001～P043 **不能作为 AF 真标签训练数据**，它们主要用于正常负样本、接触/运动伪影以及部署后的回归测试。

---

## 任务 B：训练模型替换后的短程回归测试

类型：**少量代码 + 少量实物测试。**

完成新模型后：

1. 替换 `RhythmClassifier.cpp` 中 baseline 的 `MODEL_WEIGHTS / MODEL_BIAS`；
2. 编译并烧录；
3. 确认模型字节数、RAM、Flash 和推理耗时没有异常；
4. 使用现有 P001～P043 做离线/软件回放，确认正常和伪影场景没有明显新增假报警；
5. 实物重新采 2～3 组 30～60 s 正常静止 PPG，确认端侧最终状态正常；
6. 通过后再把 `RHYTHM_MODEL_CALIBRATED` 置为 `true`。

这里不需要重新做 43 组完整 MAX30102 实验。

---

## 任务 C：最终整机回归与答辩演示

类型：**实物联调。**

不需要再做深度网络验收，但最终固件整体回归中必须顺带完成一次真实公网闭环。

建议最终完整演示链：

```text
系统开机
↓
IMU / GPS / MAX30102 等状态正常
↓
手指放置
↓
显示 HR / SpO₂ / PPG质量
↓
节律筛查给出正常状态
↓
远程网页正常收到公网数据
↓
触发 SOS 或受控模拟跌倒
↓
本地声光告警
+
远程页面 / MQTT 接收到事件
↓
解除报警
↓
恢复 NORMAL
```

这次回归时应关闭服务器演示模式，让 ESP32 使用设备账号连接 EMQX，让 ECS 使用独立只读账号订阅，再用关闭 Wi-Fi 的手机登录公网 IP。页面应显示真实运行时间、生命体征/GPS（无有效值时应如实显示）和一次 SOS 或跌倒事件。完成后保存 ESP32 串口、服务器日志和手机页面三处证据即可，不要求做多轮或长时间压力测试。

---

## 任务 D：整理最终报告材料

类型：**文档工作。**

建议最终报告至少保留四组结果：

### 跌倒检测

```text
最终阈值
双路径状态机
12 正常 + 4 跌倒独立验收混淆矩阵
离线重放结果
典型时域曲线
```

### MAX30102

```text
25 Hz 实际 FIFO 数据率
原始 PPG 与滤波 PPG
峰值 / IBI
修改前后短 IBI 对比
HR 运动后恢复趋势
SQI / valid 质量控制
```

### TinyML

```text
公开数据集
特征
训练/测试划分
混淆矩阵
Recall / F1
模型大小
ESP32 推理耗时
```

### 公网通信

```text
系统架构图
MQTT Topic
MQTTX / 远程网页截图
ECS 容器健康与 Nginx 反向代理结果
手机 4G/5G 显示真实设备数据的端到端截图
SOS / 告警远程展示
```

同时明确两个边界：

```text
1. HR/SpO₂ 为课程原型监测，不宣称医疗级测量精度；
2. 节律功能为异常筛查/疑似提示，不表述为房颤医学诊断。
```

---

# 五、当前不用继续做的事情

为了避免项目继续无边界扩展，下面这些当前可以明确停止或暂缓：

| 项目 | 当前处理 |
|---|---|
| IMU 再继续大规模采样调阈值 | 不需要，当前参数已冻结并独立验收 |
| 多轮跨网络/长时间压力测试 | 不需要；但需补一次最终实机到 ECS 手机页面的短闭环 |
| 标准血氧仪 HR/SpO₂ 精度对照 | 暂缓，不购买低质量 reference 为了凑指标 |
| LWT、ACL、8～24 h 网络长稳 | 不作为课程项目必做 |
| 医疗级 SpO₂ 标定 | 不做，当前只定位为课程原型估算 |
| 增加更多心律失常类别 | 暂不做，先完成当前 NORMAL / IRREGULAR / SUSPECTED_AF 范围 |
| LSTM / CNN / Transformer 节律模型 | 不需要，优先完成小型线性模型/MLP 的可靠训练 |
| 继续重构 ESP32 主工程 | 没有必要，当前架构已经足够稳定 |

---

# 六、推荐的最终收尾顺序

```text
当前状态
│
├─ IMU 跌倒检测 ─────────────── 已完成
│
├─ MAX30102 基础测量/信号处理 ─ 已完成
│
├─ MQTT / EMQX 固件链路 ─────── 已完成
│
├─ ECS 公网 IP 演示网页 ─────── 已完成
│
├─ 实机 → ECS → 手机短回归 ─── 待实机在场时完成
│
└─ 节律筛查
    ↓
    公开 ECG 标签 PPG 数据
    ↓
    Python 特征与训练
    ↓
    独立受试者测试
    ↓
    INT8 权重导出
    ↓
    替换 ESP32 baseline
    ↓
    少量本地回归
    ↓
    最终整机演示
    ↓
    报告整理
    ↓
    项目结束
```

因此，从现在开始，项目的主要矛盾已经不是硬件接线或 ESP32 主程序，而是：

> **把已经搭好的端侧异常节律筛查工程链，补上真正有标签的数据训练与验证，使 `model_calibrated=false` 能够有依据地变为 `true`。**

完成这一项以及最后一次包含真实公网闭环的整机回归后，本轮后续开发计划可以认为基本闭环。

此外，在公开仓库、提交课程压缩包或把工程交给他人前，应检查 `UserConfig.h` 和服务器 `.env`，删除真实 Wi-Fi、MQTT、地图和网页登录凭据，并对已经公开过的密码进行轮换。`.env` 不应进入版本库。

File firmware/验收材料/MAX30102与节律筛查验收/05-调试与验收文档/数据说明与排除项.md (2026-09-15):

# 数据说明与历史标签备注

## 1. 原始数据保留原则

验收包保留 P001～P043 全部原始 CSV，没有删除表现较差、操作不完整或质量不足的文件。
`trials.csv` 保持采集时生成的原始字段和历史标签，备注只写在本文件中，不回写原始数据。

## 2. 标准仪器对照

因没有标准心率/血氧仪，本轮取消 `reference_compare` 场景。历史 `trials.csv` 仍含空的
`hr_mae`、`spo2_mae` 兼容列，不代表进行过精度对照。

## 3. 场景标签备注

- P029～P035：CSV 历史标签为 `cane_motion`，实际操作只移动 MAX30102 模块，没有移动
  IMU。该组用于 PPG 模块/接触运动伪影分析，不能作为 IMU 运动抑制重复性证据。
- P036：`action_marked=false`，可用于连续静止波形观察，不作为严格动作起点计时样本。
- P040：记录中有较长无手指或心搏不足阶段，没有形成端侧推理窗口，原文件保留。
- P043：稳定段有效率 57.8%，但 59 个有效 IBI 均位于 500～1200 ms，且形成 3 个
  `NORMAL` 窗口。该文件作为接触不连续时的安全降级样本保留。

## 4. 结果使用限制

- 本地 `NORMAL`、`IRREGULAR` 是未校准基线模型输出，不是真实医疗标签；
- 不得把压力、移动或低质量记录标成房颤正样本；
- 不得根据本数据计算房颤召回率、特异度或临床准确率；
- HR/SpO₂ 只可用于内部趋势和稳定性分析，不得宣称已经完成标准精度校准。

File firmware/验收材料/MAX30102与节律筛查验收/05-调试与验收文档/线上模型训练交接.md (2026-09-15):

# 节律模型线上训练交接

## 1. 当前可直接复用的输入

- 原始 PPG：RED、IR；
- 滤波调试量：RED/IR DC、AC、filtered IR、envelope；
- 峰值与间隔：peak candidate、beat accepted、IBI；
- 质量与输出：finger、SQI、HR、SpO₂、valid；
- 节律上下文：状态、置信度、IBI mean、SDNN、RMSSD、pNN50、beat count；
- 运动上下文：IMU 合加速度和合角速度。

串口字段定义见 `04-Qt上位机采集代码/protocol.py`，端侧特征实现见
`03-固件关键代码/VitalsProcessor.cpp`。

## 2. 固定窗口契约

- 有效 FIFO 输出率：25 Hz；
- 特征窗口：15 秒；
- 推理间隔：5 秒；
- 最少 IBI：12；
- 节律最低 SQI：0.70；
- IMU 运动后稳定等待：15 秒；
- 当前六个模型输入：IBI CV、RMSSD/mean IBI、pNN50、最大相邻 IBI 差/mean、SQI、
  心率越界分数。

## 3. 训练数据要求

必须选择带同步 ECG 参考标签的公开 PPG 节律数据。P001～P043 只作为正常负样本、
接触压力、模块运动和端侧回放集，不作为 AF 真实标签训练集。

数据必须按受试者划分训练、验证、测试集，禁止同一受试者窗口跨集合。若公开数据只支持
二分类，应明确使用“正常/AF + 独立质量门控”；若支持其他心律失常标签，再建立正常、
其他不规则、AF 三分类映射。

## 4. 建议实现顺序

1. 实现与固件一致的峰值检测和 IBI 提取；
2. 建立 Python 与 ESP32 特征黄金样本一致性测试；
3. 生成 15 秒窗口及六维特征；
4. 先训练逻辑回归/线性分类器，再评估小型 MLP；
5. 采用受试者级独立测试集；
6. 输出 INT8 权重和偏置；
7. 替换 `RhythmClassifier.cpp` 中的基线常量；
8. 使用本地 P001～P043 回放正常场景和伪影假告警；
9. 重新记录 RAM、Flash、推理平均/P95/最大耗时；
10. 独立测试通过后，才将 `RHYTHM_MODEL_CALIBRATED` 改为 `true`。

## 5. 必须交付的指标

- 受试者数、窗口数和无效窗口比例；
- 三分类混淆矩阵或明确的二分类标签映射；
- 每类 precision、recall/sensitivity、specificity、F1；
- macro-F1、balanced accuracy，条件允许时报告 AUROC；
- 连续窗口确认前后的召回率和误报率；
- 每小时假告警数；
- INT8 前后指标差异；
- ESP32 RAM、Flash、模型字节数和推理耗时。

## 6. 禁止事项

- 不得把未校准基线输出当作真实标签；
- 不得随机按窗口切分导致受试者泄漏；
- 不得为了降低误报而删除所有异常 IBI，从而抹掉真实不规则性；
- 不得在独立测试完成前设置 `model_calibrated=true`；
- 不得将本功能描述为医疗诊断。

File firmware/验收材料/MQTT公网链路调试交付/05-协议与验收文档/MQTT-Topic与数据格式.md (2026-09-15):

# MQTT Topic 与数据格式

## 1. 基本约定

- 协议：MQTT 3.1.1；
- 传输：MQTT over TLS；
- 端口：8883；
- Topic 根路径：`smartcane/device01`；
- 订阅全部上行消息：`smartcane/device01/#`；
- JSON 数值无效时使用 `null`，不伪造传感器数据。

## 2. Topic 表

| Topic | 方向 | 内容 | 周期 / QoS | Retain |
|---|---|---|---|---|
| `smartcane/device01/presence` | 设备→云端 | `online` / `offline` | 连接状态变化，QoS 1 | 是 |
| `smartcane/device01/telemetry` | 设备→云端 | 报警、传感器在线、RSSI、运行时间 | 约 5 秒，QoS 0 | 否 |
| `smartcane/device01/vitals` | 设备→云端 | 心率、血氧、PPG 质量、节律摘要 | 约 5 秒，QoS 0 | 否 |
| `smartcane/device01/gps` | 设备→云端 | 定位来源、经纬度、卫星数 | 约 10 秒，QoS 0 | 否 |
| `smartcane/device01/event` | 设备→云端 | SOS、疑似跌倒、跌倒、节律提醒 | 状态变化立即发送，QoS 1 | 否 |
| `smartcane/device01/command` | 云端→设备 | 远程命令 | QoS 1 | 否 |

`command` 在本次交付中默认关闭，设备不会订阅该 Topic。

## 3. Payload 示例

### presence

```text
online
```

### telemetry

```json
{
  "protocol": "smartcane.mqtt",
  "version": 1,
  "online": true,
  "uptime_ms": 276994,
  "alarm": "NORMAL",
  "imu_online": true,
  "max30102_online": true,
  "rssi": -28
}
```

### vitals

```json
{
  "uptime_ms": 276994,
  "vitals": {
    "online": true,
    "finger": true,
    "valid": true,
    "signal_quality": 0.96,
    "heart_rate_bpm": 78.0,
    "spo2_pct": 99.0,
    "rhythm": {
      "state": "INSUFFICIENT_SIGNAL",
      "valid": false,
      "alert": false,
      "model_calibrated": false,
      "confidence": null
    }
  }
}
```

### gps

```json
{
  "uptime_ms": 276994,
  "gps": {
    "source": "none",
    "valid": false,
    "lat": null,
    "lon": null,
    "satellites": 0
  }
}
```

### event

```json
{
  "event": "SOS",
  "event_uptime_ms": 427034,
  "vitals": {},
  "gps": {
    "source": "none",
    "valid": false,
    "lat": null,
    "lon": null,
    "satellites": 0
  }
}
```

事件类型包括：`SUSPECTED_FALL`、`FALL`、`SOS`、`RHYTHM_SCREENING_ALERT`。

## 4. 在线判定

远程网页同时满足以下条件才显示“设备在线”：

1. Broker 已连接；
2. retained `presence` 为 `online`；
3. 最近一条 `telemetry.online` 为 `true`；
4. telemetry 距当前时间不超过 15 秒。

这种判定可避免 Broker 在线但设备已失联时仍显示正常。

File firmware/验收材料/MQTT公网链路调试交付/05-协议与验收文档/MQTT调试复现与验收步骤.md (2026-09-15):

# MQTT 调试复现与验收步骤

## 1. 准备条件

- ESP32 连接可访问互联网的 STA Wi-Fi，不能停留在 `SmartCane-Camera` 热点模式；
- Broker 支持 TLS 8883、用户名密码和 Topic ACL；
- MQTTX 使用单独的只读订阅账号；
- 设备端只允许发布自身 Topic；
- 远程命令保持关闭。

## 2. MQTTX 配置

1. 新建连接，协议选择 `mqtts://`；
2. Host 填 Broker 域名，不要带 `mqtts://` 前缀；
3. Port 填 `8883`；
4. 填写只读订阅账号和密码；
5. 开启 SSL/TLS 和证书校验；
6. MQTT Version 选择 3.1.1；
7. 开启 Auto Reconnect，Keep Alive 可设 60 秒；
8. 连接后订阅 `smartcane/device01/#`，订阅 QoS 设 1。

验收截图参考 `01-验收截图/01-MQTTX-TLS连接配置.png`。

## 3. 周期上报验收

保持设备静止在线至少 30 秒，记录各 Topic 到达时间：

- `presence`：出现 retained `online`；
- `telemetry`：约 5 秒一条；
- `vitals`：约 5 秒一条；
- `gps`：约 10 秒一条；
- telemetry 中 `imu_online`、`max30102_online` 和 `rssi` 与实际状态一致。

血氧传感器没有有效手指时，HR/SpO2 为 `null` 属于正常保护逻辑；GPS 未定位时坐标为 `null`，不能当作 `(0,0)`。

## 4. SOS 验收

1. 在安全状态下触发设备 SOS；
2. 观察本地蜂鸣器和状态变化；
3. MQTTX 应立即收到 `smartcane/device01/event`；
4. 确认 `event` 为 `SOS`，QoS 为 1；
5. 网页顶部状态应切换为“SOS 求助”；
6. 解除告警后，下一条 telemetry 应恢复 `alarm=NORMAL`。

本次实测证据见 `03-MQTTX-SOS事件-QoS1.png` 和 `05-远程监护网页-SOS状态.png`。

## 5. 运行远程网页

在 `02-远程监护网页源码` 目录打开 PowerShell：

```powershell
Copy-Item .env.example .env
```

编辑 `.env`，填写 Broker 和只读 MQTT 账号。首次运行：

```powershell
.\run.ps1 -Install
.\run.ps1
```

浏览器打开 `http://127.0.0.1:8080`。只看界面、不连接 Broker 时可运行：

```powershell
.\run.ps1 -Demo
```

## 6. 网页自动测试

```powershell
python -m unittest discover -s tests -v
```

本次共运行 7 项，全部通过，覆盖：在线判定、生命体征/GPS 解包、SOS 时间线、无效 JSON、网页鉴权、健康检查和安全响应头。

## 7. 生产发布前补测

1. 设备和电脑分别使用手机热点与另一条网络，验证真正跨网络通信；
2. 运行中关闭设备 Wi-Fi，再恢复，记录自动重连时间；
3. 设备突然断电，确认 `presence=offline` 遗嘱被 Broker 保留；
4. 分别触发 `SUSPECTED_FALL`、`FALL`、`SOS` 和节律提醒；
5. 连续运行 8—24 小时，统计丢包、重连次数和内存稳定性；
6. 记录本地事件发生时间与远端收到时间，统计端到端延迟；
7. 使用 Broker ACL 实测禁止跨设备 Topic、禁止网页账号发布命令。

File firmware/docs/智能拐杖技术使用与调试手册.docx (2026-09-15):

智能拐杖

技术使用与调试手册

基于 ESP32-S3-CAM、FreeRTOS、多传感器与 Wi-Fi 监控页面

文档版本 | V1.0
适用对象 | 项目演示、功能调试、课程答辩与日常测试
固件范围 | 避障、SOS、跌倒检测、自动照明、GPS、摄像头、网页监控
更新日期 | 2026-07-27

安全声明 本系统为教学与原型验证设备。跌倒判断、避障与 GPS 仅用于辅助提示，不能替代人工看护、医疗设备或紧急救援服务。请勿通过真实摔倒方式测试。

# 1. 使用前快速了解

本手册以当前已经编译通过的 ESP32-S3-CAM 智能拐杖固件为准，帮助使用者完成上电、联网、网页监控、传感器验证、告警解除与常见故障排查。

## 1.1 已实现功能

- HC-SR04 I2C 超声波测距与三级避障提醒。
- BH1750 环境照度检测与自动照明、手动开灯、手动关灯三种模式。
- JY901S IMU 姿态/加速度采集，以及组合规则式跌倒检测。
- ATGM336H GPS NMEA 解析、当前定位与本次上电期间的最后有效位置保存。
- 实体 SOS 按键、网页 SOS、网页解除告警，以及蜂鸣器和照明 LED 的非阻塞提示节奏。
- OV2640 摄像头网页 MJPEG 视频流、单帧抓拍与状态 JSON 接口。
- FreeRTOS 双核多任务：传感器/决策/执行在 Core 1，网络/遥测在 Core 0。
- 中文网页监控、固定高德静态地图与跳转高德详细位置链接。

## 1.2 日常使用流程

1. 确认所有模块、天线和电源线连接牢固；尤其检查 GPS、IMU 与 I2C 共地。
2. 给 ESP32-S3-CAM 上电，打开串口监视器，确认启动日志无连续报错。
3. 使用手机或电脑接入设备热点，或让设备加入已配置的路由器/手机热点。
4. 浏览器打开设备 IP 地址，确认摄像头画面、传感器卡片和控制按钮出现。
5. 依次完成超声波、照明、SOS、GPS 与摄像头测试；跌倒测试只能使用受控方式。

推荐顺序 先测试传感器和告警，再测试网络与网页；最后才进行跌倒算法的阈值校准。这样更容易定位问题。

# 2. 硬件与接线说明

## 2.1 关键接线表

功能/模块 | ESP32-S3 GPIO | 信号方向或作用 | 使用要点
I2C SDA（超声波、BH1750、OLED 共用） | GPIO41 | 双向数据线 | 所有 I2C 模块共地；SDA/SCL 上拉应为 3.3 V。
I2C SCL（超声波、BH1750、OLED 共用） | GPIO42 | 时钟线 | I2C 地址通常为：超声波 0x57、OLED 0x3C、BH1750 为 0x23 或 0x5C。
JY901S TX | GPIO39（ESP RX） | IMU -> ESP32 | TX/RX 必须交叉连接；默认 9600 bps。
JY901S RX | GPIO38（ESP TX） | ESP32 -> IMU | 若只读取 IMU 数据，可保留但建议仍接好。
ATGM336H TX | GPIO47（ESP RX） | GPS -> ESP32 | GPS 数据进入 ESP32 的关键线路。
ATGM336H RX | GPIO21（ESP TX） | ESP32 -> GPS | 用于 GPS 配置/命令通道。
SOS 实体按键 | GPIO40 | 按下为高电平 | 按下触发；已锁存告警时再按一次解除。
蜂鸣器控制 | GPIO1 | 高电平响 | 通过 MOS 驱动，不要把蜂鸣器负载直接接到普通 GPIO。
照明/提示 LED | GPIO14 | 高电平亮 | 同时承担夜间照明与部分告警闪烁提示。

## 2.2 供电与安全检查

- GPS 模块推荐 VCC 接 ESP32 的 3V3，GND 接 ESP32 GND；GPS TX 接 GPIO47，GPS RX 接 GPIO21。
- ESP32-S3 的 GPIO 不耐受 5 V。任何模块的 TX、SDA 或 SCL 若输出 5 V，必须先经电平转换。
- 摄像头启动和 Wi-Fi 发射会产生电流峰值。若摄像头黑屏、重启或 GPS 掉线，优先检查 5 V 电源余量与地线。
- 板载相机占用 GPIO4、5、6、7、8、9、10、11、12、13、15、16、17、18 等固定引脚，禁止将外设接到这些相机引脚上。

# 3. 编译、上传与串口监视

## 3.1 PlatformIO 操作

6. 在 VS Code 中打开 SmartCane 工程文件夹，确认 PlatformIO 环境为 esp32-s3-cam。
7. 先点击 Build。首次构建会下载 ESP32 平台、工具链和 Arduino 框架；已下载完成的包会保存在本机缓存中，后续一般不会重复下载。
8. 看到 [SUCCESS] 后，连接开发板并在 PlatformIO 中选择正确的 COM 口，再点击 Upload。
9. 上传完成后，使用 115200 波特率打开串口监视器；如串口被占用，先关闭其他串口工具或已打开的监视器。

## 3.2 启动日志的判断

日志或现象 | 表示什么 | 下一步
[SmartCane] boot | 固件已启动。 | 继续观察 I2C、GPS、相机和 FreeRTOS 日志。
[BH1750] online / [Sonar] online / [OLED] online | 对应 I2C 模块已被识别。 | 若显示 not found，检查地址、供电、SDA/SCL 和共地。
[GPS] parser started at 9600 bps | GPS 解析器已经以 9600 bps 启动。 | 这不等于已定位，仍需观察 gps.valid 和卫星数。
[Camera] PSRAM=... | 摄像头初始化流程已运行。 | camera=true 表示初始化成功；画面仍需由 /stream 实测。
[FreeRTOS] Sensor/Decision/Actuator=Core1, Network/Telemetry=Core0 | 多任务已启动。 | 可继续进行网页和传感器联调。
[SUCCESS] 后出现 PowerShell profile 脚本禁用提示 | Windows PowerShell 配置提示，与 PlatformIO 已成功构建无关。 | 只要前面已显示 [SUCCESS]，无需因这条提示重新编译。

## 3.3 无法上传时

若提示 Could not open COMx、port is busy 或拒绝访问，通常是串口正在被 PlatformIO Monitor、Arduino 串口监视器、其他调试工具占用，或 COM 号已变化。关闭占用程序，重新插拔数据线，在设备管理器确认当前 COM 号后再 Upload。

# 4. 联网与网页监控教程

## 4.1 两种联网方式

方式 | 连接方法 | 网页地址 | 适用场景
设备热点（AP） | 手机/电脑连接 SmartCane-Camera 热点；密码以 UserConfig.h 的 AP_PASSWORD 为准。 | 通常为 http://192.168.4.1/ | 离线演示、现场直连。设备热点本身不提供互联网。
路由器/手机热点（STA） | 在 UserConfig.h 中配置 WIFI_SSID 与 WIFI_PASSWORD，设备上电后会尝试连接。 | 串口、OLED 或状态行显示的实际 IP | 需要加载高德地图、手机和设备可同时联网的场景。

设备连接已配置路由器失败约 12 秒后，会自动降级为自身热点。网页卡片中的 IP 即当前应访问的地址。

## 4.2 打开网页

10. 连接设备所在网络后，在浏览器输入网页 IP，例如设备热点模式的 http://192.168.4.1/。
11. 网页标题应为“智能拐杖监控”。初次进入时，摄像头视频流会自动尝试从 :81/stream 加载。
12. 上传新固件或修改网页后，如仍看到旧界面，请按 Ctrl+F5 强制刷新，或关闭浏览器标签后重新打开。

## 4.3 网页区域与标识含义

区域/标识 | 含义 | 正常或异常判断
摄像头画面 | 来自端口 81 的 MJPEG 实时视频流。 | 有连续画面即正常；黑屏或网络异常时见第 10 章排查。
状态 | 当前最高优先级告警状态。 | 颜色：NORMAL 绿色；CAUTION/WARNING/DANGER 黄色；SOS/FALL 红色。
距离 cm | 超声波当前有效距离。 | -- 表示暂未获得有效数据或传感器离线。
光照 lx | BH1750 环境照度。 | 低于 20 lx 且为自动模式时，照明灯会点亮。
GPS | 定位状态文字。 | 定位、信号中断、搜索卫星、未定位分别表示不同 GNSS 状态。
底部详情行 | IP、GPS 坐标/卫星、IMU 在线情况、照明状态与模式。 | IMU 显示离线时，系统不会把无效 IMU 数据当作跌倒。
位置地图 | 固定高德静态地图。 | 绿色点为实时位置；黄色点为最后有效位置；地图不可拖动或缩放。

# 5. 按钮、告警与照明说明

## 5.1 网页按钮

按钮 | 作用 | 使用后的表现
SOS 求助 | 触发并锁存 SOS 告警。 | 状态变为 SOS（红色），蜂鸣器和 LED 按 SOS 节奏闪烁；摄像头进入事件优先图传。
解除告警 | 解除 SOS 与 FALL 两种锁存告警，并重置跌倒检测器。 | 若前方仍有近障，避障提醒会按当前距离重新出现。
开灯 | 设置手动常开照明。 | 照明 LED 保持亮；网页中“开灯”按钮显示选中轮廓。
关灯 | 设置手动常关照明。 | 会关闭普通夜间照明；但 SOS、FALL、DANGER 的可视告警闪烁不会被抑制。
自动照明 | 按 BH1750 照度自动控制照明。 | 低于 20 lx 自动点亮；高于阈值则关闭。

## 5.2 实体 SOS 按键

GPIO40 的实体按键使用“按下切换”逻辑，并经过约 30 ms 消抖。松开按键没有动作，长按不会连续触发。

- 当前没有 SOS/FALL 锁存：按下一次，触发 SOS 并持续保持。
- 当前已经有 SOS 或 FALL 锁存：再按下一次，请求解除锁存。
- 解除后若障碍物仍处于警戒范围，系统会继续显示相应的避障状态；这不是解除失败。

## 5.3 告警优先级、蜂鸣器与 LED

状态机始终只对最高优先级状态输出提示：SOS > FALL > DANGER（<30 cm）> WARNING（<50 cm）> CAUTION（<100 cm）> NORMAL。超声波恢复时使用 5 cm 回差，避免在临界距离反复跳变。

状态 | 网页颜色 | 蜂鸣器节奏 | LED 行为
NORMAL | 绿色 | 不响 | 仅由手动/自动照明决定。
CAUTION | 黄色 | 约每 1.1 秒短响一次 | 不作为避障闪烁输出。
WARNING | 黄色 | 约每 0.65 秒短响一次 | 不作为避障闪烁输出。
DANGER | 黄色 | 约每 0.35 秒响一次 | 约每 0.35 秒闪烁。
FALL | 红色 | 约每 0.8 秒响一次 | 约每 0.8 秒闪烁，直到解除。
SOS | 红色 | 约每 0.4 秒响一次 | 约每 0.4 秒闪烁，直到解除。

提示 DANGER、FALL、SOS 时 LED 的闪烁优先级高于普通照明设置；因此在告警期间点击“关灯”不会让安全提示灯熄灭。

# 6. 避障与跌倒检测原理

## 6.1 避障判断

距离范围 | 状态 | 解除条件 | 用途
< 30 cm | DANGER | 距离达到 35 cm 以上后才降级 | 危险接近，蜂鸣和 LED 高频提示。
30 cm 至 < 50 cm | WARNING | 距离达到 55 cm 以上后才降级 | 中等距离提醒。
50 cm 至 < 100 cm | CAUTION | 距离达到 105 cm 以上后才解除 | 提前提醒使用者注意前方障碍。
≥ 100 cm | NORMAL | 无 | 无近障告警。

若距离数据失效，系统会退出近障状态，避免使用过期距离持续告警。超声波只能辅助测距，易受目标材质、角度、软质物体与安装方向影响，应以实测为准。

## 6.2 跌倒检测逻辑（演示初值）

跌倒检测不是单一阈值，而是按时间顺序组合 IMU 事件，以减少普通行走或拿起拐杖造成的误报。当前参数均在 UserConfig.h 中集中管理，必须按实际使用数据校准。

阶段 | 当前规则 | 初始阈值
候选事件 | 出现低重力或较大冲击时进入候选。 | 低重力 ≤ 0.55 g；冲击 ≥ 2.20 g。
冲击确认 | 候选窗口中必须观察到冲击。 | 候选窗口 1.5 s。
倾倒与静止 | 横滚角或俯仰角明显倾斜，且陀螺仪合速度较低。 | |roll| 或 |pitch| ≥ 55°；陀螺合速度 ≤ 35 °/s。
持续确认 | 倾倒并静止状态必须连续保持。 | 保持 ≥ 800 ms。
触发与冷却 | 满足条件后锁存 FALL，短时间内不重复判定。 | 冷却 3 s。

禁止事项 不要让人真实摔倒来测试。推荐将拐杖固定在软垫上，以受控的小幅度动作模拟“冲击后倾斜静止”，并全程有人看护。

## 6.3 跌倒测试与调参建议

13. 先记录正常行走、正常放下拐杖、转身、跨台阶等 IMU 数据，确认不会误触发。
14. 在软垫与人工看护条件下，模拟冲击、倾斜和静止的顺序，观察 fall_latched 是否变为 true。
15. 若误报过多，可提高冲击阈值、增大倾角保持时间或降低静止阈值；每次只改一个参数。
16. 若漏报，可适当降低冲击阈值或缩短保持时间，但必须重新验证正常使用场景。

# 7. GPS、地图与摄像头

## 7.1 GPS 状态含义

网页文字 | 含义 | 建议操作
定位 | 当前 NMEA 数据有效，网页显示实时经纬度与卫星数。 | 可查看高德静态地图和详细地图链接。
信号中断 | 当前失去有效定位，但本次上电期间曾成功定位。 | 网页保留最后有效位置；检查天空视野和天线。
搜索卫星 | GPS 有时间或卫星相关数据，但尚未形成有效定位。 | 到室外开阔处静置，避免天线被金属或人体遮挡。
未定位 | 尚无可用定位数据。 | 检查供电、共地、GPS TX -> GPIO47 与波特率。

GPS 的当前定位与最后有效位置都来自 WGS-84 坐标。最后有效位置只保存在本次上电的 RAM 中，断电或重启后会清空。首次冷启动、遮挡、天线方向和电源噪声都可能让定位时间变长或中断；不应把“曾经定位过”理解为始终具有可靠定位。

## 7.2 高德地图显示

- 网页底部为固定高德静态地图，不支持拖动、缩放或手势操作。
- 实时定位时显示绿色标记；GPS 暂时失锁时，显示最后有效位置的黄色标记。
- 为减少地图服务请求，网页以约 100 米粒度刷新静态地图；点击“在高德地图中打开”可查看完整精度位置。
- 静态地图由手机/电脑浏览器直接从互联网加载。若手机仅连接 ESP32 独立热点且无法上网，地图无法加载是正常现象；避障、SOS、照明等本地功能不受影响。

## 7.3 摄像头与抓拍

地址 | 用途 | 说明
http://设备IP/ | 中文监控主页 | 自动加载 MJPEG 视频、状态与控制按钮。
http://设备IP:81/stream | MJPEG 视频流 | 用于浏览器或上位机直接查看视频。
http://设备IP/capture | 单帧 JPEG 抓拍 | 返回一张当前相机图像；用于排查视频流问题。
http://设备IP/api/status | 状态 JSON | 供网页和上位机读取距离、照度、IMU、GPS、告警与网络状态。

串口 JSON 中 camera=true 仅表示摄像头初始化成功；若 /capture 能返回图片但主页视频黑屏，优先检查浏览器缓存、:81 端口访问、手机网络和页面刷新。

# 8. 传感器与功能测试步骤

## 8.1 推荐测试顺序

序号 | 操作 | 预期结果 | 失败时优先检查
1 | 上电并打开 115200 串口 | 启动日志出现；已接 I2C 模块显示 online。 | 供电、USB 数据线、串口 COM 号。
2 | 将障碍物在 1 m、50 cm、30 cm 附近移动 | CAUTION/WARNING/DANGER 随距离变化；危险区 LED 闪烁。 | 超声波地址 0x57、I2C、安装方向。
3 | 遮住 BH1750，再恢复光照 | 自动模式下低照度点灯，恢复光照后熄灭。 | BH1750 地址、阈值 20 lx、当前是否为自动模式。
4 | 网页依次点击开灯、关灯、自动照明 | 照明模式改变，选中轮廓随之变化。 | 网页是否刷新到新固件、/api/light 命令。
5 | 正常状态按实体 SOS 一次 | SOS 锁存，蜂鸣器和 LED 持续节奏提示。 | GPIO40、高电平按下、按键接线。
6 | SOS/FALL 状态再按实体按键或网页解除告警 | 锁存解除；若仍近障则返回避障状态。 | 按键消抖、命令队列、距离读数。
7 | 室外开阔处静置 GPS | gps.valid=true、经纬度、卫星数和地图出现。 | GPS 天线、3V3/GND、TX -> GPIO47、9600 bps。
8 | 打开主页与 /capture | 主页有视频；抓拍至少能获得单帧。 | 电源、相机排线、浏览器和端口 81。

## 8.2 串口遥测与命令

串口波特率为 115200。系统会周期输出以 SC1 TEL 开头的 JSON，例如 alarm、distance_cm、lux、camera、imu、gps、last_fix 等字段。常用命令如下：

串口输入 | 作用
SC1 CMD SOS | 触发并锁存 SOS。
SC1 CMD CANCEL | 解除 SOS/FALL 锁存，并重置跌倒检测器。
SC1 CMD LIGHT ON | 手动常开照明。
SC1 CMD LIGHT OFF | 手动常关普通照明。
SC1 CMD LIGHT AUTO | 按 BH1750 照度自动照明。

# 9. 常见故障排查

现象 | 可能原因 | 处理方法
Build 提示缺少工具链/框架包 | PlatformIO 首次下载不完整或网络较慢。 | 保持网络/代理可用，等待依赖下载；中断后已完整下载的包通常会被缓存。
Upload 提示 COM 口忙或拒绝访问 | 串口被监视器或其他程序占用。 | 关闭 Monitor/Arduino 串口工具，确认当前 COM 口后重试。
I2C devices: none 或模块 not found | 未供电、SDA/SCL 接反、地址不符、未共地。 | 逐个模块接入；确认 GPIO41/42、3.3 V 上拉和对应地址。
网页能打开但视频黑屏 | 视频流端口 81 未连接、浏览器缓存或相机供电不稳。 | 按 Ctrl+F5；直接打开 :81/stream 与 /capture；检查 5 V 供电。
/capture 显示 capture failed | 相机未正确取到帧或供电不足。 | 重新上电；检查相机排线、PSRAM/板型配置和电源。
GPS 有 NMEA 但没有经纬度 | 已收数据但尚未获得卫星定位。 | 到开阔室外等待；天线朝上，远离摄像头/Wi-Fi 天线和金属遮挡。
GPS 完全无 NMEA | GPS TX、共地、供电或波特率不对。 | 确认 GPS TX -> GPIO47、GND 共地、3V3；临时打开波特率诊断。
高德地图空白 | 浏览器没有互联网、地图 Key 配置或服务请求失败。 | 确保手机/电脑能上网；不要公开地图 Key；检查本地 UserConfig.h 配置。
网页开关灯无效 | 浏览器仍为旧缓存，或命令没有发到新固件。 | Upload 后 Ctrl+F5；确认页面按钮和 light_mode 是否更新。

## 9.1 GPS 波特率诊断

当前 GPS 默认波特率是 9600。若怀疑模块实际波特率不同，可将 UserConfig.h 中 GPS_BAUD_DIAGNOSTIC_ON_BOOT 临时改为 true，上传后重启。系统会依次测试常见波特率，并在串口打印校验正确的 NMEA 语句；确认后务必改回 false，以避免每次启动额外等待。

## 9.2 需要保护的配置

- WIFI_SSID、WIFI_PASSWORD、AP_PASSWORD 和 AMAP_STATIC_MAP_KEY 都存放在 UserConfig.h。
- 准备公开代码、截图、论文附录或提交仓库前，应替换真实网络凭据和地图 Key。
- 网页静态地图需要将地图 Key 下发给浏览器；请只授予必要服务权限，并在高德控制台关注配额。

# 10. 验收清单

以下清单可作为课堂演示、答辩或阶段验收记录。每项均建议记录日期、现场条件和异常备注。

检查项 | 通过标准 | 结果（勾选/备注）
固件构建 | PlatformIO 显示 [SUCCESS]，无编译错误。 | □ 通过 □ 不通过 备注：
串口与启动 | 115200 串口可读，I2C/IMU/GPS/相机启动信息合理。 | □ 通过 □ 不通过 备注：
超声波避障 | 不同距离正确进入三级提示，危险区蜂鸣和 LED 闪烁。 | □ 通过 □ 不通过 备注：
自动与手动照明 | 低照度自动亮；网页三种模式均可切换。 | □ 通过 □ 不通过 备注：
实体 SOS | 按一次锁存 SOS，再按一次解除。 | □ 通过 □ 不通过 备注：
网页 SOS/解除 | 网页可锁存 SOS 并立即解除 SOS/FALL。 | □ 通过 □ 不通过 备注：
跌倒检测 | 受控模拟符合规则时出现 FALL；正常操作不应频繁误报。 | □ 通过 □ 不通过 备注：
GPS 与地图 | 室外可获得定位；失星时能显示最后有效位置。 | □ 通过 □ 不通过 备注：
摄像头 | 主页 MJPEG 视频与 /capture 单帧均可工作。 | □ 通过 □ 不通过 备注：

交付建议 答辩演示前，先在室内完成避障、照明、SOS 与摄像头，再到室外完成 GPS 定位。将地图、视频和传感器结果分阶段展示，可靠性更高。

ESP32-S3-CAM 智能拐杖 | 第 页

智能拐杖技术使用与调试手册 | 当前固件功能基线

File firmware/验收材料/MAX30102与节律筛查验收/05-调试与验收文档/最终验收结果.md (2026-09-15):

# MAX30102 峰值算法修改后最终验收

## 1. 验收对象

最终验收使用烧录修改后固件采集的 P041、P042、P043。修改目标是消除静止状态下的
重复峰、异常短 IBI 和旧 HR 长时间保持有效的问题。

## 2. 传输链路

| 试验 | 样本 | 时长/s | 采样率 | 丢帧 | 最大间隔/ms | FIFO溢出 |
|---|---:|---:|---:|---:|---:|---:|
| P041 | 3293 | 131.84 | 25.0 Hz | 0 | 50 | 0 |
| P042 | 2170 | 86.88 | 25.0 Hz | 0 | 50 | 0 |
| P043 | 1868 | 74.79 | 25.0 Hz | 0 | 50 | 0 |

链路验收通过。

## 3. 信号与IBI结果

| 试验 | 稳定段有效率 | 稳定段SQI | 有效IBI | IBI中位数/ms | IBI CV | `<500 ms` | `>1200 ms` |
|---|---:|---:|---:|---:|---:|---:|---:|
| P041 | 86.3% | 0.940 | 113 | 890 | 0.070 | 0 | 0 |
| P042 | 83.4% | 0.926 | 71 | 850 | 0.058 | 0 | 0 |
| P043 | 57.8% | 0.898 | 59 | 880 | 0.100 | 0 | 0 |

P041、P042 达到稳定段有效率不低于 80% 的工程目标。P043 接触连续性较差，最长连续
有效段约 7.6 秒；新固件按设计将旧 HR 置为无效，没有继续输出陈旧值。三组被接受的
IBI 均未出现短间隔或长间隔异常，峰值一致性修改通过。

## 4. 节律状态与性能

| 试验 | 推理次数 | `NORMAL` | `IRREGULAR` | `INCONCLUSIVE` | `SUSPECTED_AF` |
|---|---:|---:|---:|---:|---:|
| P041 | 17 | 17 | 0 | 0 | 0 |
| P042 | 9 | 9 | 0 | 0 | 0 |
| P043 | 3 | 3 | 0 | 0 | 0 |
| 合计 | 29 | 29 | 0 | 0 | 0 |

29 次推理耗时平均 65.6 μs，P95 为 95.4 μs，最大 106 μs。当前权重仍是未校准集成
基线，以上结果用于验证端侧链路和本机正常场景误报，不构成模型准确率证明。

## 5. 与修改前对比

修改前部分静止记录存在 6%～34% 的小于 500 ms IBI，IBI CV 约 0.21～0.37，且在
漏峰后旧 HR 可能继续保持有效。修改后最终三组：

- 小于 500 ms IBI 从非零降为 0；
- 大于 1200 ms IBI 为 0；
- IBI CV 降至 0.058～0.100；
- 静止窗口未出现低级或严重节律误报；
- 心搏不连续时主动降级为无效，而非维持旧 HR。

## 6. 最终判定

MAX30102 本地原始采集、滤波、峰值检测、IBI、HR趋势、SpO₂原型估算、SQI门控、
节律窗口和端侧性能调试完成，可以交付线上同学开展公开数据训练和权重替换。

未完成且明确延期的项目：标准仪器 HR/SpO₂ 精度对照、ECG 标签模型训练、独立受试者
测试集指标和医疗器械级验证。

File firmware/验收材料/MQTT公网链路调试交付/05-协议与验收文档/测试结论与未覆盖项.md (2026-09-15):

# MQTT 测试结论与未覆盖项

## 1. 当前证据矩阵

| 验收项 | 结论 | 证据 |
|---|---|---|
| TLS 8883 配置 | 已验证 | MQTTX 配置截图、固件连接日志 |
| Broker 连接 | 已验证 | 串口日志出现 `connected`，遥测最终为 `ONLINE` |
| 周期 telemetry/vitals/gps | 已验证 | MQTTX 周期消息截图 |
| presence 在线判定 | 间接验证 | 网页只有 presence 在线且 telemetry 新鲜时才显示设备在线 |
| SOS 事件 QoS 1 | 已验证 | MQTTX SOS 截图 |
| 网页正常数据显示 | 已验证 | 正常状态截图，HR 78、SpO2 99、质量 96% |
| 网页 SOS 状态 | 已验证 | SOS 状态截图 |
| 网页消息解析及安全基础 | 已验证 | 7 项自动测试全部通过 |
| 远程命令关闭 | 已核对 | 固件配置为 `false`，网页无控制入口 |
| 自动重连实现 | 代码已实现 | 固件和网页均配置自动重连 |
| 强制断网后的实际重连时间 | 未留存充分证据 | 需补做断网—恢复测试 |
| 遗嘱 `offline` | 代码已实现，未单独实测 | 需突然断电并观察 retained presence |
| 真正跨不同网络 | 未留存充分证据 | 需设备和电脑使用不同出口网络 |
| FALL / SUSPECTED_FALL 公网事件 | 未在本包中留存截图 | 当前仅 SOS 有直接 MQTTX 证据 |
| 长时间稳定性 | 未验证 | 建议连续运行 8—24 小时 |
| Topic ACL 拒绝测试 | 未验证 | 需在 Broker 控制台配置并测试 |

## 2. 可交付范围

对于课程作业或原型验收，可以表述为：

> 已完成智能拐杖 MQTT 公网上行链路与远程监护网页，实现设备在线状态、周期遥测、生命体征、GPS 和 SOS 事件的公网传输；实测 MQTTX 可接收 QoS 1 SOS，网页可实时显示正常与求助状态。远程控制默认关闭。

不要表述为“已完成生产级全场景公网可靠性验证”，因为跨网络、遗嘱、全部事件、ACL 拒绝和长稳测试尚无完整证据。

## 3. 串口日志边界

原始串口会话约 27 分钟。最后一帧 MQTT 仍为 `ONLINE`，随后电脑端串口出现“拒绝访问”。这只能说明 TTL 串口被其他程序占用或连接被中断，不能解释为设备 MQTT 离线。

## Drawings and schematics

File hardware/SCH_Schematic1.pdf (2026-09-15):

最小系统板 | GNSS | 扩展板子 I2C总线 | 蜂鸣器

# IMU

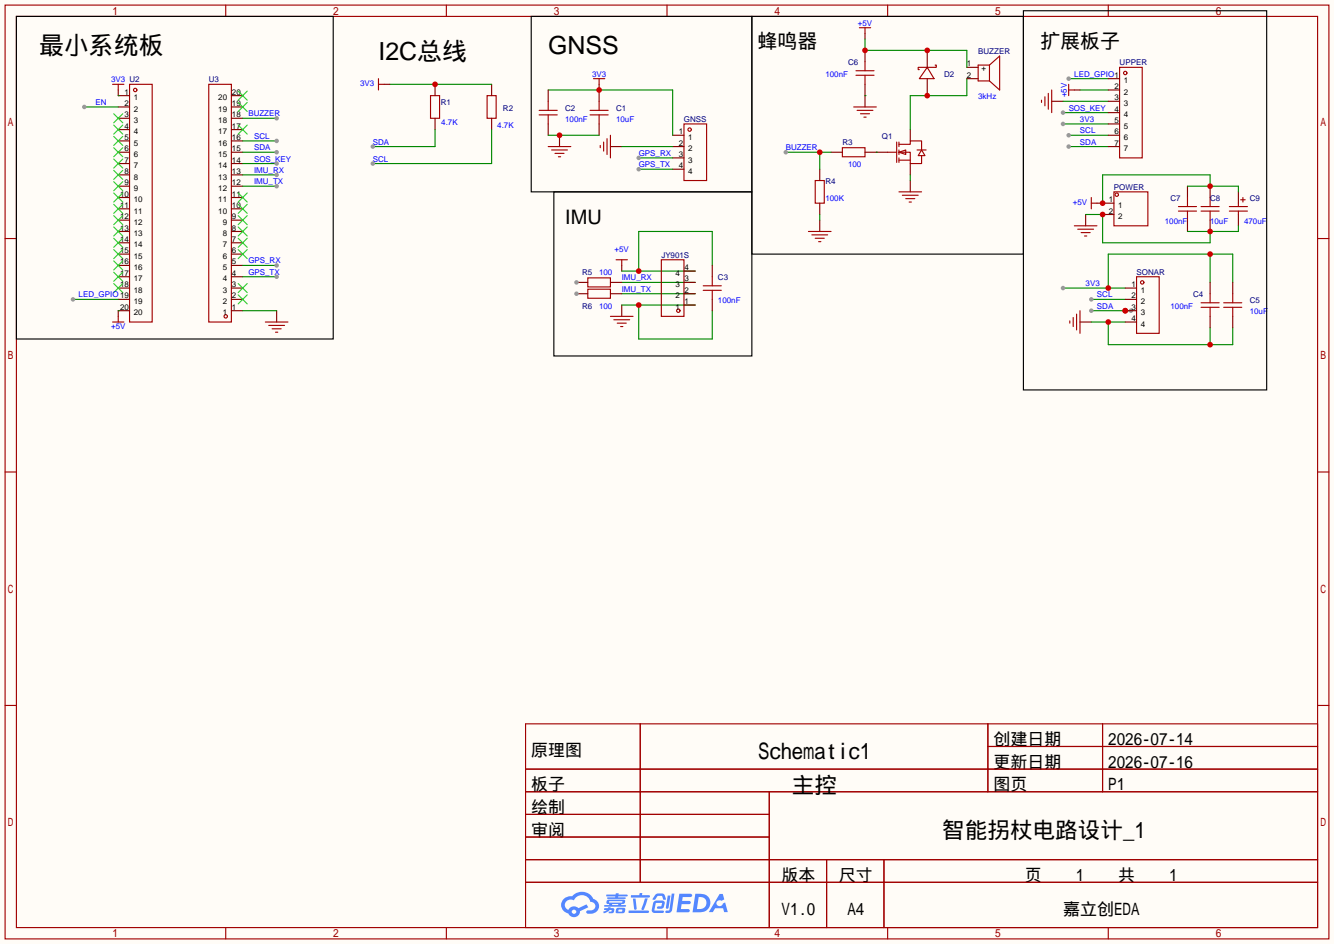
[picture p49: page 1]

原理图 | Schematic1 | 创建日期 | 2026-07-14

更新日期 | 2026-07-16

板子 | 主控 | 图页 | P1
绘制 | | 智能拐杖电路设计_1
审阅

V1.0 | A4 | 嘉立创EDA

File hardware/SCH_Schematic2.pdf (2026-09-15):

# 光敏传感器

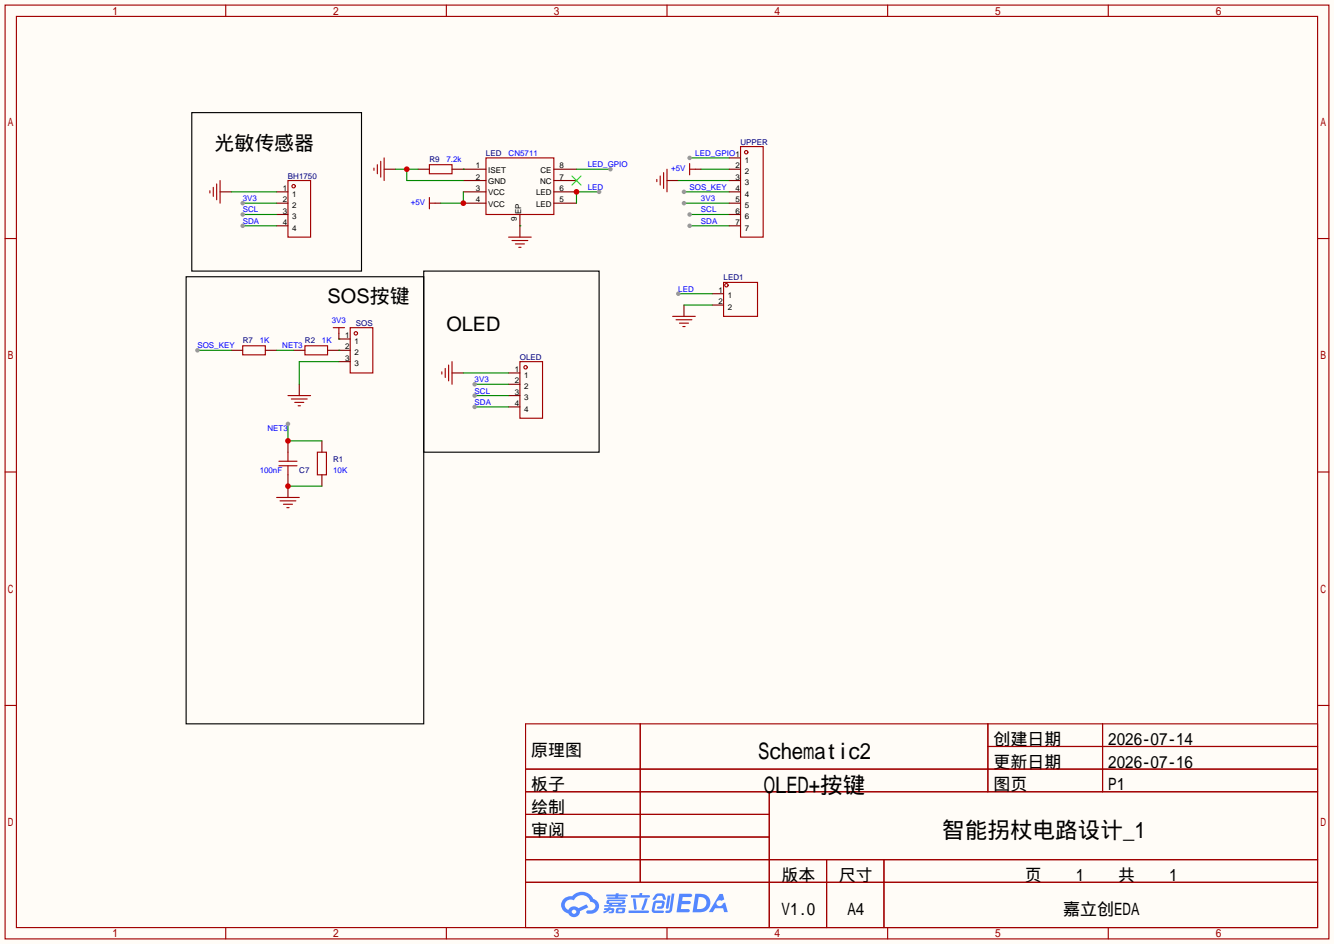
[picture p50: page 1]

原理图 | Schematic2 | 创建日期 | 2026-07-14
板子 | OLED+按键 | 图页 | P1
绘制 | | 智能拐杖电路设计_1
审阅

更新日期 | 2026-07-16

V1.0 | A4 | 嘉立创EDA

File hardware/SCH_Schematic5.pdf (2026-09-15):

# 升压模块

# 电源模块

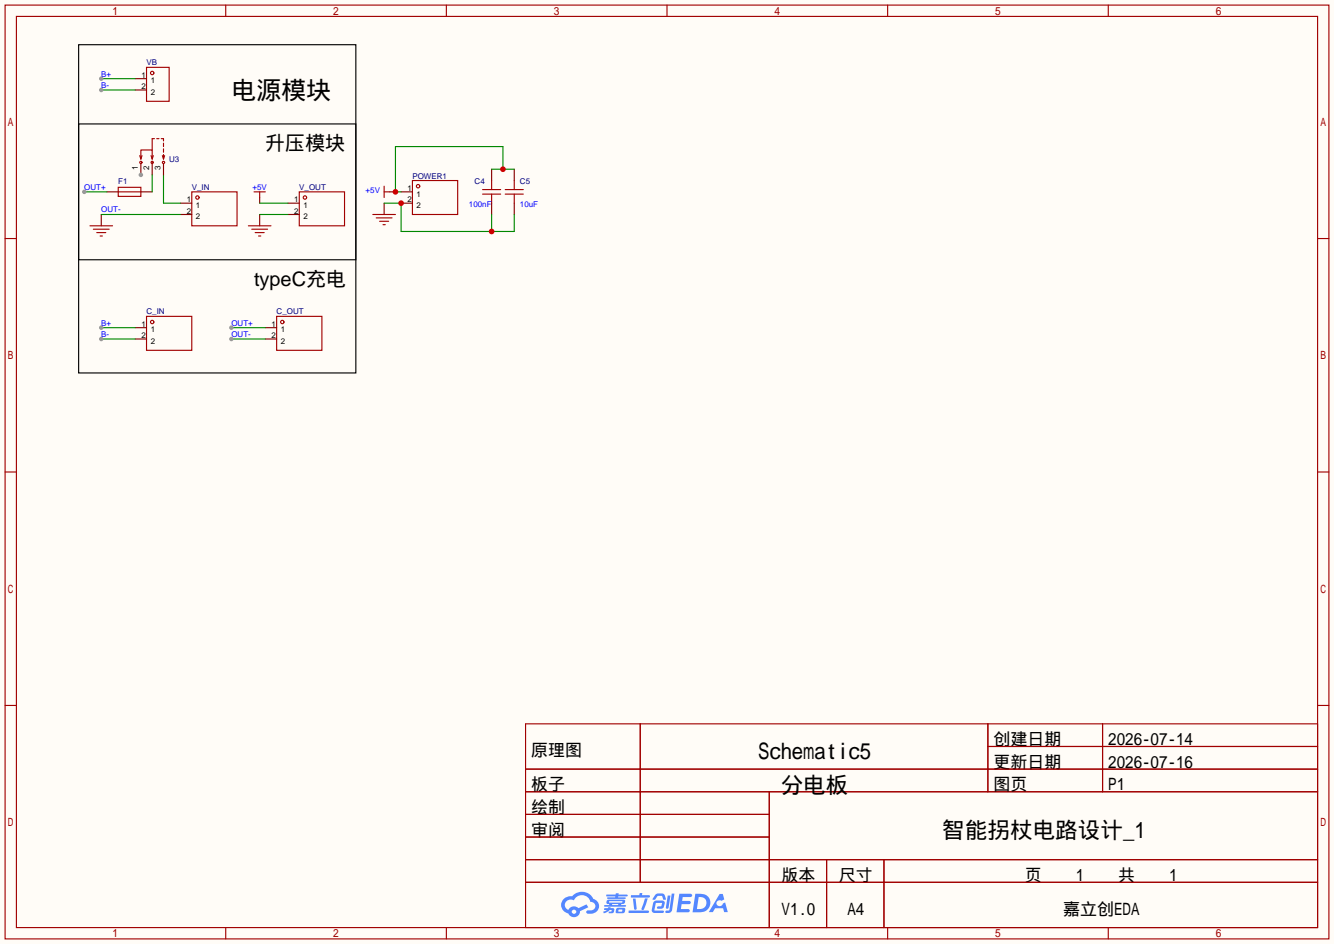
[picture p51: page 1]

原理图 | Schematic5 | 创建日期 | 2026-07-14

更新日期 | 2026-07-16

板子 | 分电板 | 图页 | P1
绘制 | | 智能拐杖电路设计_1
审阅

V1.0 | A4 | 嘉立创EDA

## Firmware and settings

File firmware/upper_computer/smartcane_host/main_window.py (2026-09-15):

"""SmartCane 三栏监控主窗口：传感器/控制、Wi-Fi 图传、GPS 地图。"""

from __future__ import annotations

import math
import os
import shutil
import time
from datetime import datetime
from pathlib import Path
from typing import Any, TextIO

from PyQt5.QtCore import Qt, QTimer
from PyQt5.QtGui import QColor, QFont, QImage, QPainter, QPixmap
from PyQt5.QtWidgets import (
    QCheckBox,
    QComboBox,
    QFileDialog,
    QFrame,
    QGridLayout,
    QHBoxLayout,
    QLabel,
    QLineEdit,
    QMainWindow,
    QMessageBox,
    QPushButton,
    QScrollArea,
    QSizePolicy,
    QSplitter,
    QTextEdit,
    QVBoxLayout,
    QWidget,
)
from serial.tools import list_ports

from .camera_worker import CameraWorker, normalize_base_url
from .diagnostics import CheckState, DiagnosticsEngine, best_serial_port
from .imu_capture import ImuCaptureSession, SCENARIOS, campaign_metrics
from .imu_plot import ImuPlotWidget
from .map_widget import MapWidget
from .ppg_capture import PpgCaptureSession, PPG_SCENARIOS
from .ppg_plot import PpgPlotWidget
from .serial_worker import SerialWorker
from .track_import import TrackImportError, load_track


# 固件使用稳定英文枚举值传输，界面层只负责映射为中文显示。
ALARM_LABELS = {
    "NORMAL": "正常",
    "CAUTION": "注意障碍",
    "WARNING": "近障警告",
    "DANGER": "危险近障",
    "SUSPECTED_FALL": "疑似跌倒",
    "FALL": "跌倒告警",
    "SOS": "SOS 求救",
}


class MetricCard(QFrame):
    """统一的“名称 + 数值 + 单位”传感器卡片。"""

    def __init__(self, title: str, unit: str = "", parent=None):
        super().__init__(parent)
        self.setObjectName("metricCard")
        layout = QVBoxLayout(self)
        layout.setContentsMargins(12, 10, 12, 10)
        layout.setSpacing(2)
        caption = QLabel(title)
        caption.setObjectName("metricCaption")
        self.value = QLabel("—")
        self.value.setObjectName("metricValue")
        self.unit = QLabel(unit)
        self.unit.setObjectName("metricUnit")
        row = QHBoxLayout()
        row.setContentsMargins(0, 0, 0, 0)
        row.addWidget(self.value)
        row.addWidget(self.unit)
        row.addStretch(1)
        layout.addWidget(caption)
        layout.addLayout(row)

    def set_value(self, value: str, online: bool = True) -> None:
        self.value.setText(value)
        self.setProperty("online", online)
        self.style().unpolish(self)
        self.style().polish(self)


class MainWindow(QMainWindow):
    """协调串口线程、图传线程和地图组件；不在上位机内执行算法判断。"""

    def __init__(self, demo: bool = False):
        super().__init__()
        self.demo = demo
        self.serial_worker: SerialWorker | None = None
        self._retired_serial_workers: list[SerialWorker] = []
        self.camera_worker: CameraWorker | None = None
        self.current_pixmap = QPixmap()
        self.current_jpeg = b""
        self.last_telemetry_at = 0.0
        self.packet_count = 0
        self.frame_count = 0
        self.frame_started_at = 0.0
        self._camera_address_user_edited = False
        self._demo_phase = 0.0
        self.diagnostics = DiagnosticsEngine()
        self.diagnostic_rows: dict[str, QLabel] = {}
        self.session_log_path: Path | None = None
        self._session_log: TextIO | None = None
        self._auto_connect_after = 0.0
        self._last_auto_candidate = ""
        self.imu_capture = ImuCaptureSession()
        self._demo_imu_sequence = 0
        self.ppg_capture = PpgCaptureSession()
        self._demo_ppg_sequence = 0
        self._latest_ppg_context: dict[str, Any] = {}

        self.setWindowTitle("SmartCane 智能拐杖上位机")
        self.resize(1680, 940)
        self.setMinimumSize(1180, 720)
        self._build_ui()
        self._apply_style()
        self.refresh_ports()

        self.health_timer = QTimer(self)
        self.health_timer.setInterval(1000)
        self.health_timer.timeout.connect(self._check_telemetry_age)
        self.health_timer.start()
        self.port_timer = QTimer(self)
        self.port_timer.setInterval(1500)
        self.port_timer.timeout.connect(self._poll_ports)
        if not demo:
            self.port_timer.start()
        if demo:
            QTimer.singleShot(250, self.start_demo)

    def _build_ui(self) -> None:
        """组装顶部状态、三栏主区域和底部通信日志。"""
        root = QWidget(self)
        root_layout = QVBoxLayout(root)
        root_layout.setContentsMargins(18, 14, 18, 14)
        root_layout.setSpacing(10)

        heading = QHBoxLayout()
        title_box = QVBoxLayout()
        title = QLabel("SmartCane · 实时监控中心")
        title.setObjectName("title")
        subtitle = QLabel("串口遥测  ·  Wi-Fi 图传  ·  GPS 地图")
        subtitle.setObjectName("subtitle")
        title_box.addWidget(title)
        title_box.addWidget(subtitle)
        heading.addLayout(title_box)
        heading.addStretch(1)
        self.global_status = QLabel("等待设备连接")
        self.global_status.setObjectName("globalStatus")
        heading.addWidget(self.global_status)
        root_layout.addLayout(heading)

        splitter = QSplitter(Qt.Horizontal)
        splitter.setChildrenCollapsible(False)
        splitter.addWidget(self._build_sensor_panel())
        splitter.addWidget(self._build_camera_panel())
        splitter.addWidget(self._build_map_panel())
        splitter.setSizes([390, 700, 580])
        root_layout.addWidget(splitter, 1)

        log_bar = QHBoxLayout()
        log_title = QLabel("串口原始日志与运行记录")
        log_title.setObjectName("sectionTitle")
        self.log_file_label = QLabel("尚未创建日志文件")
        self.log_file_label.setObjectName("muted")
        self.log_file_label.setToolTip("连接串口后自动创建 UTF-8 日志")
        open_logs = QPushButton("打开日志目录")
        open_logs.clicked.connect(self.open_log_folder)
        export_log = QPushButton("导出本次日志")
        export_log.clicked.connect(self.export_log)
        clear_log = QPushButton("清空显示")
        clear_log.clicked.connect(lambda: self.log.clear())
        log_bar.addWidget(log_title)
        log_bar.addWidget(self.log_file_label, 1)
        log_bar.addWidget(open_logs)
        log_bar.addWidget(export_log)
        log_bar.addWidget(clear_log)
        root_layout.addLayout(log_bar)

        self.log = QTextEdit()
        self.log.setObjectName("log")
        self.log.setReadOnly(True)
        self.log.document().setMaximumBlockCount(1200)
        self.log.setMaximumHeight(190)
        self.log.setPlaceholderText("连接后自动抓取启动日志、SC1 协议消息和错误信息")
        root_layout.addWidget(self.log)
        self.setCentralWidget(root)

    def _build_sensor_panel(self) -> QWidget:
        scroll = QScrollArea()
        scroll.setWidgetResizable(True)
        scroll.setFrameShape(QFrame.NoFrame)
        panel = QWidget()
        layout = QVBoxLayout(panel)
        layout.setContentsMargins(0, 0, 6, 0)
        layout.setSpacing(10)

        connection = self._section("串口连接")
        connection_layout = connection.layout()
        port_row = QHBoxLayout()
        self.port_combo = QComboBox()
        self.port_combo.setMinimumWidth(130)
        refresh = QPushButton("刷新")
        refresh.clicked.connect(self.refresh_ports)
        self.serial_button = QPushButton("连接")
        self.serial_button.setObjectName("primaryButton")
        self.serial_button.clicked.connect(self.toggle_serial)
        port_row.addWidget(self.port_combo, 1)
        port_row.addWidget(refresh)
        port_row.addWidget(self.serial_button)
        self.serial_status = QLabel("未连接 · 115200 bit/s")
        self.serial_status.setObjectName("muted")
        self.auto_connect = QCheckBox("自动发现并连接 USB-TTL（自动排除蓝牙串口）")
        self.auto_connect.setChecked(True)
        connection_layout.addLayout(port_row)
        connection_layout.addWidget(self.serial_status)
        connection_layout.addWidget(self.auto_connect)
        layout.addWidget(connection)

        diagnostics = self._section("自动自检")
        self.diagnostic_overall = QLabel("等待设备连接")
        self.diagnostic_overall.setObjectName("diagnosticOverall")
        self.diagnostic_overall.setProperty("state", CheckState.WAITING.value)
        diagnostics.layout().addWidget(self.diagnostic_overall)
        diagnostics_grid = QGridLayout()
        diagnostics_grid.setHorizontalSpacing(8)
        diagnostics_grid.setVerticalSpacing(4)
        for row, result in enumerate(self.diagnostics.results()):
            name = QLabel(result.label)
            name.setObjectName("fieldName")
            state = QLabel("● 等待")
            state.setObjectName("diagnosticState")
            state.setProperty("state", result.state.value)
            state.setToolTip(result.detail)
            self.diagnostic_rows[result.key] = state
            diagnostics_grid.addWidget(name, row, 0)
            diagnostics_grid.addWidget(state, row, 1)
        diagnostics.layout().addLayout(diagnostics_grid)
        reset_diagnostics = QPushButton("重新开始自检")
        reset_diagnostics.clicked.connect(self.reset_diagnostics)
        diagnostics.layout().addWidget(reset_diagnostics)
        layout.addWidget(diagnostics)

        cards = QGridLayout()
        cards.setSpacing(8)
        self.alarm_card = MetricCard("系统状态")
        self.distance_card = MetricCard("前方距离", "cm")
        self.lux_card = MetricCard("环境光照", "lx")
        self.rssi_card = MetricCard("Wi-Fi 信号", "dBm")
        cards.addWidget(self.alarm_card, 0, 0, 1, 2)
        cards.addWidget(self.distance_card, 1, 0)
        cards.addWidget(self.lux_card, 1, 1)
        cards.addWidget(self.rssi_card, 2, 0)
        self.satellite_card = MetricCard("GPS 卫星", "颗")
        cards.addWidget(self.satellite_card, 2, 1)
        self.heart_rate_card = MetricCard("心率估算", "bpm")
        self.spo2_card = MetricCard("血氧估算", "%")
        self.ppg_quality_card = MetricCard("PPG 质量", "%")
        self.rhythm_card = MetricCard("节律筛查")
        cards.addWidget(self.heart_rate_card, 3, 0)
        cards.addWidget(self.spo2_card, 3, 1)
        cards.addWidget(self.ppg_quality_card, 4, 0)
        cards.addWidget(self.rhythm_card, 4, 1)
        layout.addLayout(cards)

        imu = self._section("JY901S 姿态与惯性")
        imu_grid = QGridLayout()
        self.imu_values: dict[str, QLabel] = {}
        imu_fields = [
            ("ax_g", "AX", "g"), ("ay_g", "AY", "g"), ("az_g", "AZ", "g"),
            ("gyro_x_dps", "GX", "°/s"), ("gyro_y_dps", "GY", "°/s"),
            ("gyro_z_dps", "GZ", "°/s"), ("roll_deg", "横滚", "°"),
            ("pitch_deg", "俯仰", "°"), ("yaw_deg", "航向", "°"),
        ]
        for index, (key, name, unit) in enumerate(imu_fields):
            name_label = QLabel(name)
            name_label.setObjectName("fieldName")
            value = QLabel("—")
            value.setObjectName("fieldValue")
            self.imu_values[key] = value
            cell = QHBoxLayout()
            cell.addWidget(name_label)
            cell.addStretch(1)
            cell.addWidget(value)
            cell.addWidget(QLabel(unit))
            imu_grid.addLayout(cell, index // 3, index % 3)
        imu.layout().addLayout(imu_grid)
        layout.addWidget(imu)

        capture = self._section("跌倒检测 · 高频 IMU 数据采集")
        capture_form = QGridLayout()
        capture_form.addWidget(QLabel("试验编号"), 0, 0)
        self.capture_trial = QLineEdit("T001")
        self.capture_trial.setPlaceholderText("例如 T001")
        capture_form.addWidget(self.capture_trial, 0, 1)
        capture_form.addWidget(QLabel("场景标签"), 1, 0)
        self.capture_scene = QComboBox()
        for display, label, ground_truth in SCENARIOS:
            self.capture_scene.addItem(display, (label, ground_truth))
        capture_form.addWidget(self.capture_scene, 1, 1)
        capture.layout().addLayout(capture_form)

        capture_buttons = QHBoxLayout()
        self.capture_start_button = QPushButton("开始记录")
        self.capture_start_button.setObjectName("primaryButton")
        self.capture_start_button.clicked.connect(self.start_imu_capture)
        self.capture_mark_button = QPushButton("动作开始")
        self.capture_mark_button.clicked.connect(self.mark_imu_action)
        self.capture_mark_button.setEnabled(False)
        self.capture_stop_button = QPushButton("停止并保存")
        self.capture_stop_button.clicked.connect(lambda: self.stop_imu_capture())
        self.capture_stop_button.setEnabled(False)
        capture_buttons.addWidget(self.capture_start_button)
        capture_buttons.addWidget(self.capture_mark_button)
        capture_buttons.addWidget(self.capture_stop_button)
        capture.layout().addLayout(capture_buttons)

        self.capture_status = QLabel("未记录 · CSV 将保存到 imu_captures")
        self.capture_status.setObjectName("muted")
        self.capture_stats = QLabel("样本 0 · 采样率 — Hz · 丢帧 0 · 最大间隔 — ms")
        self.capture_stats.setObjectName("fieldValue")
        self.capture_campaign_stats = QLabel("累计：等待试验数据")
        self.capture_campaign_stats.setObjectName("muted")
        capture.layout().addWidget(self.capture_status)
        capture.layout().addWidget(self.capture_stats)
        capture.layout().addWidget(self.capture_campaign_stats)
        self.imu_plot = ImuPlotWidget()
        capture.layout().addWidget(self.imu_plot)
        plot_note = QLabel("青色 A / 橙色 G / 紫色 Tilt；红色虚线为当前固件阈值")
        plot_note.setObjectName("muted")
        capture.layout().addWidget(plot_note)
        open_captures = QPushButton("打开 CSV 目录")
        open_captures.clicked.connect(self.open_capture_folder)
        capture.layout().addWidget(open_captures)
        layout.addWidget(capture)
        self.refresh_campaign_metrics()

        ppg_capture = self._section("MAX30102 · PPG/血氧数据采集")
        ppg_form = QGridLayout()
        ppg_form.addWidget(QLabel("试验编号"), 0, 0)
        self.ppg_trial = QLineEdit("P001")
        self.ppg_trial.setPlaceholderText("例如 P001")
        ppg_form.addWidget(self.ppg_trial, 0, 1)
        ppg_form.addWidget(QLabel("测试场景"), 1, 0)
        self.ppg_scene = QComboBox()
        for display, label, expected_state in PPG_SCENARIOS:
            self.ppg_scene.addItem(display, (label, expected_state))
        ppg_form.addWidget(self.ppg_scene, 1, 1)
        ppg_capture.layout().addLayout(ppg_form)

        ppg_buttons = QHBoxLayout()
        self.ppg_start_button = QPushButton("开始记录")
        self.ppg_start_button.setObjectName("primaryButton")
        self.ppg_start_button.clicked.connect(self.start_ppg_capture)
        self.ppg_mark_button = QPushButton("动作/放指开始")
        self.ppg_mark_button.clicked.connect(self.mark_ppg_action)
        self.ppg_mark_button.setEnabled(False)
        self.ppg_stop_button = QPushButton("停止并保存")
        self.ppg_stop_button.clicked.connect(lambda: self.stop_ppg_capture())
        self.ppg_stop_button.setEnabled(False)
        ppg_buttons.addWidget(self.ppg_start_button)
        ppg_buttons.addWidget(self.ppg_mark_button)
        ppg_buttons.addWidget(self.ppg_stop_button)
        ppg_capture.layout().addLayout(ppg_buttons)

        self.ppg_capture_status = QLabel("未记录 · CSV 将保存到 ppg_captures")
        self.ppg_capture_status.setObjectName("muted")
        self.ppg_capture_stats = QLabel("样本 0 · 目标 25 Hz · 丢帧 0 · FIFO 溢出 0")
        self.ppg_capture_stats.setObjectName("fieldValue")
        self.ppg_quality_stats = QLabel("手指 — · 有效 — · SQI —")
        self.ppg_quality_stats.setObjectName("muted")
        ppg_capture.layout().addWidget(self.ppg_capture_status)
        ppg_capture.layout().addWidget(self.ppg_capture_stats)
        ppg_capture.layout().addWidget(self.ppg_quality_stats)
        self.ppg_plot = PpgPlotWidget()
        ppg_capture.layout().addWidget(self.ppg_plot)
        ppg_note = QLabel(
            "红/青：RED/IR AC；橙：滤波 IR；白线：接受的脉搏峰；紫：SQI；"
            "硬件 100 SPS 经 4 点平均后 FIFO 实际为 25 Hz"
        )
        ppg_note.setWordWrap(True)
        ppg_note.setObjectName("muted")
        ppg_capture.layout().addWidget(ppg_note)
        open_ppg = QPushButton("打开 PPG CSV 目录")
        open_ppg.clicked.connect(self.open_ppg_capture_folder)
        ppg_capture.layout().addWidget(open_ppg)
        layout.addWidget(ppg_capture)

        controls = self._section("设备控制（串口）")
        control_grid = QGridLayout()
        sos = QPushButton("触发 SOS")
        sos.setObjectName("dangerButton")
        sos.clicked.connect(self._confirm_sos)
        cancel = QPushButton("解除锁存告警")
        cancel.clicked.connect(lambda: self._send("cancel"))
        auto = QPushButton("照明自动")
        auto.clicked.connect(lambda: self._send("light_auto"))
        light_on = QPushButton("照明开启")
        light_on.clicked.connect(lambda: self._send("light_on"))
        light_off = QPushButton("照明关闭")
        light_off.clicked.connect(lambda: self._send("light_off"))
        ping = QPushButton("通信测试")
        ping.clicked.connect(lambda: self._send("ping"))
        control_grid.addWidget(sos, 0, 0)
        control_grid.addWidget(cancel, 0, 1)
        control_grid.addWidget(auto, 1, 0)
        control_grid.addWidget(light_on, 1, 1)
        control_grid.addWidget(light_off, 2, 0)
        control_grid.addWidget(ping, 2, 1)
        controls.layout().addLayout(control_grid)
        layout.addWidget(controls)
        layout.addStretch(1)
        scroll.setWidget(panel)
        return scroll

    def _build_camera_panel(self) -> QWidget:
        panel = QFrame()
        panel.setObjectName("panel")
        layout = QVBoxLayout(panel)
        layout.setContentsMargins(14, 14, 14, 14)
        layout.setSpacing(10)
        heading = QLabel("OV2640 · Wi-Fi 实时图传")
        heading.setObjectName("panelTitle")
        layout.addWidget(heading)
        row = QHBoxLayout()
        self.camera_url = QLineEdit("http://192.168.4.1")
        self.camera_url.setPlaceholderText("http://设备IP")
        self.camera_url.textEdited.connect(lambda: setattr(self, "_camera_address_user_edited", True))
        self.camera_button = QPushButton("连接图传")
        self.camera_button.setObjectName("primaryButton")
        self.camera_button.clicked.connect(self.toggle_camera)
        row.addWidget(self.camera_url, 1)
        row.addWidget(self.camera_button)
        layout.addLayout(row)

        self.image_label = QLabel("等待 Wi-Fi 图像…")
        self.image_label.setObjectName("cameraImage")
        self.image_label.setAlignment(Qt.AlignCenter)
        self.image_label.setMinimumSize(420, 360)
        self.image_label.setSizePolicy(QSizePolicy.Expanding, QSizePolicy.Expanding)
        layout.addWidget(self.image_label, 1)
        stats = QHBoxLayout()
        self.camera_status = QLabel("未连接")
        self.camera_status.setObjectName("muted")
        self.camera_stats = QLabel("帧 0  ·  — KiB  ·  — fps")
        self.camera_stats.setObjectName("fieldValue")
        save = QPushButton("保存当前帧")
        save.clicked.connect(self.save_frame)
        stats.addWidget(self.camera_status, 1)
        stats.addWidget(self.camera_stats)
        stats.addWidget(save)
        layout.addLayout(stats)
        return panel

    def _build_map_panel(self) -> QWidget:
        panel = QFrame()
        panel.setObjectName("panel")
        layout = QVBoxLayout(panel)
        layout.setContentsMargins(14, 14, 14, 14)
        layout.setSpacing(10)
        heading = QLabel("ATGM336H · GPS 地图")
        heading.setObjectName("panelTitle")
        layout.addWidget(heading)
        gps_grid = QGridLayout()
        self.gps_values: dict[str, QLabel] = {}
        for index, (key, name) in enumerate(
            [("lat", "纬度"), ("lon", "经度"), ("speed_kmh", "速度 km/h"),
             ("altitude_m", "海拔 m"), ("utc", "UTC"), ("fix", "定位")]
        ):
            gps_grid.addWidget(QLabel(name), index // 2, (index % 2) * 2)
            value = QLabel("—")
            value.setObjectName("fieldValue")
            self.gps_values[key] = value
            gps_grid.addWidget(value, index // 2, (index % 2) * 2 + 1)
        layout.addLayout(gps_grid)
        self.map_widget = MapWidget()
        self.map_widget.setMinimumSize(380, 380)
        layout.addWidget(self.map_widget, 1)
        controls = QHBoxLayout()
        import_button = QPushButton("导入地图/轨迹")
        import_button.clicked.connect(self.import_track)
        clear_button = QPushButton("清除导入")
        clear_button.clicked.connect(self.map_widget.clear_track)
        trail_button = QPushButton("清除实时轨迹")
        trail_button.clicked.connect(self.map_widget.clear_live_trail)
        self.follow_gps = QCheckBox("跟随 GPS")
        self.follow_gps.setChecked(True)
        self.follow_gps.toggled.connect(self.map_widget.set_follow)
        controls.addWidget(import_button)
        controls.addWidget(clear_button)
        controls.addWidget(trail_button)
        controls.addStretch(1)
        controls.addWidget(self.follow_gps)
        layout.addLayout(controls)
        note = QLabel("在线底图：OpenStreetMap；支持 GeoJSON / GPX / KML 导入")
        note.setObjectName("muted")
        layout.addWidget(note)
        return panel

    @staticmethod
    def _section(title: str) -> QFrame:
        frame = QFrame()
        frame.setObjectName("section")
        layout = QVBoxLayout(frame)
        layout.setContentsMargins(12, 10, 12, 12)
        layout.setSpacing(8)
        label = QLabel(title)
        label.setObjectName("sectionTitle")
        layout.addWidget(label)
        return frame

    def refresh_ports(self) -> list[Any]:
        """重新枚举系统串口；data 保存真实 COM 名，文本仅供用户识别。"""
        current = self.port_combo.currentData()
        self.port_combo.clear()
        ports = sorted(list_ports.comports(), key=lambda item: item.device)
        for port in ports:
            label = f"{port.device}  ·  {port.description}"
            self.port_combo.addItem(label, port.device)
        if not ports:
            self.port_combo.addItem("未发现串口", "")
        elif current:
            index = self.port_combo.findData(current)
            if index >= 0:
                self.port_combo.setCurrentIndex(index)
        return ports
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

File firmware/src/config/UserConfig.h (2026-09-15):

#pragma once

#include <Arduino.h>

// User-adjustable runtime parameters.  Alarm and fall values are initial
// classroom-demo values only: validate against recordings from this cane before
// relying on them in demonstrations, and never treat them as a safety guarantee.
namespace Config {

constexpr char WIFI_SSID[] = "";
constexpr char WIFI_PASSWORD[] = "";
constexpr char AP_SSID[] = "SmartCane-Camera";
constexpr char AP_PASSWORD[] = "12345678";
constexpr uint32_t WIFI_CONNECT_TIMEOUT_MS = 12000;

// 高德 Web 服务 Key：用于网页中的只读静态定位地图。该 Key 会随网页下发到
// 浏览器，因此请仅授予静态地图所需权限，并留意高德控制台中的调用配额。
constexpr char AMAP_STATIC_MAP_KEY[] = "";

constexpr bool CAMERA_VFLIP = false;
constexpr bool CAMERA_HMIRROR = false;

// Current bench profile: OLED and ultrasonic module are not installed.
// Keep them disabled so the ultrasonic driver's 0x57 probe cannot mistake the
// MAX30102 (which uses the same address) for a distance sensor.
constexpr bool SONAR_ENABLED = false;
constexpr bool OLED_ENABLED = false;
constexpr uint8_t SONAR_I2C_ADDRESS = 0x57;
constexpr uint8_t OLED_I2C_ADDRESS = 0x3C;
constexpr uint32_t SONAR_INTERVAL_MS = 220;
constexpr uint32_t LIGHT_INTERVAL_MS = 500;
constexpr uint32_t DISPLAY_INTERVAL_MS = 250;
constexpr uint32_t TELEMETRY_INTERVAL_MS = 200;

// Obstacle thresholds in centimetres; keep them in descending order.
constexpr float OBSTACLE_CAUTION_CM = 100.0f;
constexpr float OBSTACLE_WARNING_CM = 50.0f;
constexpr float OBSTACLE_DANGER_CM = 30.0f;
// A zone only relaxes after this extra clearance, preventing alarm chatter
// when an ultrasonic measurement fluctuates near a boundary.
constexpr float OBSTACLE_HYSTERESIS_CM = 5.0f;
constexpr float DARK_LUX_THRESHOLD = 20.0f;

// Frozen prototype profile selected after replaying three rounds / 48 recorded
// trials.  The strict path still requires an impact.  A second, longer hold
// path accepts a deeply sampled low-g event even when the 10 Hz JY901S stream
// misses the impact peak.  This is not a safety guarantee.
constexpr float FALL_FREE_FALL_G = 0.55f;
constexpr float FALL_DEEP_FREE_FALL_G = 0.40f;
constexpr float FALL_IMPACT_G = 2.20f;
constexpr float FALL_TILT_DEG = 55.0f;
constexpr float FALL_STILL_GYRO_DPS = 45.0f;
constexpr uint32_t FALL_SEQUENCE_WINDOW_MS = 2000;
constexpr uint32_t FALL_TILT_HOLD_MS = 600;
constexpr uint32_t FALL_DEEP_TILT_HOLD_MS = 1200;
constexpr uint32_t FALL_COOLDOWN_MS = 3000;

static_assert(FALL_DEEP_FREE_FALL_G <= FALL_FREE_FALL_G,
              "deep free-fall threshold must be no greater than free-fall");
static_assert(FALL_TILT_HOLD_MS <= FALL_SEQUENCE_WINDOW_MS,
              "strict fall hold must fit inside the sequence window");
static_assert(FALL_DEEP_TILT_HOLD_MS <= FALL_SEQUENCE_WINDOW_MS,
              "deep fall hold must fit inside the sequence window");

// A detected IMU fall pattern first enters SUSPECTED_FALL. The user may cancel
// it from the existing physical button or web-page cancel button before it
// becomes the latched FALL alarm. This is intentionally timestamp-based rather
// than delay()-based, so the other FreeRTOS tasks keep running.
constexpr uint32_t SUSPECTED_FALL_CONFIRM_MS = 4000;
constexpr uint32_t FALL_CANCEL_COOLDOWN_MS = 3000;

// The currently connected MAX30102 is on the primary GPIO41/42 bus. Using that
// bus also leaves the ESP32-S3's second hardware I2C controller available for
// the camera SCCB link. Before enabling the 0x57 ultrasonic module, separate
// the two 0x57 devices with an I2C multiplexer or move one to software I2C.
constexpr bool MAX30102_ENABLED = true;
constexpr bool MAX30102_USE_PRIMARY_I2C = true;
constexpr uint8_t MAX30102_I2C_ADDRESS = 0x57;
constexpr uint16_t MAX30102_SAMPLE_RATE_HZ = 100;
constexpr uint8_t MAX30102_LED_CURRENT = 0x24; // initial, tune with PPG data
constexpr uint8_t MAX30102_MAX_FIFO_SAMPLES_PER_UPDATE = 6;
constexpr uint32_t MAX30102_RETRY_MS = 5000;
constexpr uint32_t MAX30102_STALE_MS = 1500;
constexpr uint32_t MAX30102_SPO2_WINDOW_MS = 4000;
constexpr uint32_t MAX30102_FINGER_IR_THRESHOLD = 50000;
constexpr float MAX30102_MIN_RELATIVE_AMPLITUDE = 0.0020f;
constexpr float MAX30102_VALID_QUALITY_MIN = 0.45f;
constexpr float MAX30102_HEART_RATE_MIN_BPM = 40.0f;
constexpr float MAX30102_HEART_RATE_MAX_BPM = 180.0f;

static_assert(!(MAX30102_ENABLED && MAX30102_USE_PRIMARY_I2C && SONAR_ENABLED),
              "MAX30102 and sonar both use address 0x57; separate their buses");
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

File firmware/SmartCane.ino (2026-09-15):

/**
 * @file SmartCane.ino
 * @brief Arduino IDE 构建入口。
 *
 * 与 src/main.cpp 二选一生效；所有硬件初始化和数据调度均由 SmartCaneApp
 * 负责，入口文件不承载业务逻辑。
 */
#ifndef SMARTCANE_PLATFORMIO
#include "src/app/SmartCaneApp.h"

SmartCaneApp app;

void setup() {
  app.begin();
}

void loop() {
  // update() 为非阻塞轮询接口，应高频调用。
  app.update();
}
#endif

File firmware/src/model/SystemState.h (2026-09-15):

#pragma once

#include <Arduino.h>
#include <math.h>

/**
 * @file SystemState.h
 * @brief 驱动层、控制层、通信层之间共享的原始数据契约。
 *
 * 后续算法优先读取 SensorSnapshot：数值单位已统一，valid 表示当前可用，
 * updatedAtMs 用于判断数据新鲜度。无效浮点字段保持 NAN，禁止当作 0 使用。
 */
struct ImuReading {
  float axG = NAN;      // X 轴加速度，单位 g
  float ayG = NAN;
  float azG = NAN;
  float gyroX = NAN;    // X 轴角速度，单位 °/s
  float gyroY = NAN;
  float gyroZ = NAN;
  float rollDeg = NAN;  // 欧拉角，单位 °
  float pitchDeg = NAN;
  float yawDeg = NAN;
  uint32_t updatedAtMs = 0; // 最近一组完整数据的 millis() 时间戳
  bool valid = false;       // true 仅表示驱动已得到当前有效帧

  float accelerationMagnitudeG() const {
    return sqrtf(axG * axG + ayG * ayG + azG * azG);
  }
};

struct GpsReading {
  double latitude = NAN;  // WGS-84 纬度，北纬为正
  double longitude = NAN;
  float speedKmh = NAN;   // 地速，km/h
  float altitudeM = NAN;  // 海拔，m
  uint8_t satellites = 0;
  char utc[11] = "--:--:--";
  uint32_t updatedAtMs = 0;
  bool valid = false;
};

// The PPG rhythm result is deliberately a screening result, never a medical
// diagnosis.  The three terminal classes are generated only after a stable
// signal window and a consecutive-window confirmation policy.
enum class RhythmScreenState : uint8_t {
  Disabled,
  NoSensor,
  NoFinger,
  Collecting,
  MotionArtifact,
  Inconclusive,
  Normal,
  Irregular,
  SuspectedAf
};

inline const char *rhythmScreenName(RhythmScreenState state) {
  switch (state) {
  case RhythmScreenState::Disabled: return "DISABLED";
  case RhythmScreenState::NoSensor: return "NO_SENSOR";
  case RhythmScreenState::NoFinger: return "NO_FINGER";
  case RhythmScreenState::Collecting: return "COLLECTING";
  case RhythmScreenState::MotionArtifact: return "MOTION_ARTIFACT";
  case RhythmScreenState::Inconclusive: return "INCONCLUSIVE";
  case RhythmScreenState::Normal: return "NORMAL";
  case RhythmScreenState::Irregular: return "IRREGULAR";
  case RhythmScreenState::SuspectedAf: return "SUSPECTED_AF";
  default: return "INCONCLUSIVE";
  }
}

// The bounded feature vector shared by VitalsProcessor and RhythmClassifier.
// It carries no raw PPG samples, which keeps both the classifier and public
// telemetry small and avoids exporting an unnecessary biometric waveform.
struct RhythmFeatures {
  float heartRateBpm = NAN;
  float ibiMeanMs = NAN;
  float ibiStdMs = NAN;       // SDNN for the rolling IBI window
  float ibiCv = NAN;
  float rmssdMs = NAN;
  float pnn50 = NAN;          // 0.0 ~ 1.0
  float maxAdjacentDiffMs = NAN;
  float signalQuality = 0.0f;
  uint32_t windowDurationMs = 0;
  uint8_t beatCount = 0;
  bool sensorOnline = false;
  bool fingerPresent = false;
  bool ppgValid = false;
  bool ready = false;
};

struct RhythmScreeningReading {
  RhythmScreenState state = RhythmScreenState::Disabled;
  float confidence = 0.0f;       // probability-like model confidence, 0~1
  float ibiMeanMs = NAN;
  float sdnnMs = NAN;
  float rmssdMs = NAN;
  float pnn50 = NAN;
  uint32_t updatedAtMs = 0;
  uint32_t inferenceUs = 0;
  uint32_t inferenceCount = 0;
  uint16_t modelBytes = 0;
  uint16_t classifierStateBytes = 0;
  uint8_t beatCount = 0;
  bool modelAvailable = false;
  // false for the bundled integration baseline.  It becomes true only after
  // its weights have been replaced with an ECG-referenced, validated model.
  bool modelCalibrated = false;
  bool valid = false;
  bool alertActive = false;
};

// MAX30102 PPG-derived, non-medical vital-sign snapshot. `valid` requires a
// stable finger signal, a usable waveform and plausible calculated values.
struct VitalsReading {
  float heartRateBpm = NAN;
  float spo2Pct = NAN;
  float signalQuality = 0.0f; // 0.0 ~ 1.0
  uint32_t rawRed = 0;
  uint32_t rawIr = 0;
  uint32_t updatedAtMs = 0;
  bool sensorOnline = false;
  bool fingerPresent = false;
  bool valid = false;
  RhythmScreeningReading rhythm;
};

struct SensorSnapshot {
  float distanceCm = NAN; // 前向距离，cm
  uint32_t distanceUpdatedAtMs = 0;
  bool sonarOnline = false;
  bool distanceValid = false;

  float lux = NAN;        // 环境照度，lx
  uint32_t luxUpdatedAtMs = 0;
  bool lightSensorOnline = false;
  bool luxValid = false;

  ImuReading imu;
  GpsReading gps;          // 当前 GNSS 状态；失星后 valid 会变为 false。
  GpsReading lastValidGps; // 本次上电以来最后一次有效定位，供断星回退显示。
  bool lastValidGpsAvailable = false;
  VitalsReading vitals;
};

enum class AlarmKind : uint8_t {
  None,
  ObstacleCaution,
  ObstacleWarning,
  ObstacleDanger,
  SuspectedFall,
  Fall,
  Sos
};

// A decision-task output.  It is intentionally a value object so it can cross
// a FreeRTOS queue without sharing mutable controller state with the task that
// owns the GPIOs.
struct ActuatorIntent {
  SensorSnapshot sensors;
  AlarmKind alarm = AlarmKind::None;
  bool buzzerOn = false;
  bool lightOn = false;
  bool sosLatched = false;
  bool suspectedFall = false;
  bool fallLatched = false;
  int8_t manualLightMode = -1; // -1 auto, 0 off, 1 on
  bool incidentActive = false;
};

inline const char *alarmName(AlarmKind alarm) {
  switch (alarm) {
  case AlarmKind::ObstacleCaution: return "CAUTION";
  case AlarmKind::ObstacleWarning: return "WARNING";
  case AlarmKind::ObstacleDanger: return "DANGER";
  case AlarmKind::SuspectedFall: return "SUSPECTED_FALL";
  case AlarmKind::Fall: return "FALL";
  case AlarmKind::Sos: return "SOS";
  default: return "NORMAL";
  }
}
